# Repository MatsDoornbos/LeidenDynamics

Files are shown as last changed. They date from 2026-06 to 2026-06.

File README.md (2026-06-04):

# Leiden Dynamics Smart Sprinkler System

**Team:** Mats Doornbos, Justin Gruijters, Lucas Idsinga, Benard Wanyande
**Institution:** Leiden University (MSc Robotics)

**Availability Notice:** This repository and all associated files, code, and documentation will remain publicly available and accessible until at least August 31st, 2026.

---

## Repository Contents

*   `Turret_Demo.py`: The main autonomous execution script for scanning, targeting, and firing.
*   `Turret_Calibration.py`: The script used to generate the required trajectory lookup table.
*   `Reloading_Water.py`: A utility script for manually opening and closing the water relay.
*   `/Designs/`: Directory containing CAD models (STEP files) and assembly diagrams for the 3D-printed turret and A-frame fluid system.
*   `SmartSprinkler.mp4`: Video demonstration of the final working system.

## System Requirements

### Hardware Configuration
The software is written specifically for a Raspberry Pi connected to the custom 3D-printed turret and passive-pressure syringe system. Ensure your wiring matches the following configuration for data and power.

**GPIO Pinout (BCM):**
*   **Yaw (Pan) Stepper Motor:** Pins 6, 13, 19, 26
*   **Pitch (Tilt) Stepper Motor:** Pins 12, 16, 20, 21
*   **Pitch Limit Switch (Vertical Home):** Pin 1 (Wired to Ground)
*   **Yaw IR Sensor (Horizontal Home):** Pin 24
*   **Valve Relay:** Pin 25

**Power Supply Wiring:**
*   **5V Power Supply:** Connected directly to the motor power pins to drive the two stepper motors.
*   **12V Power Supply:** Connected via the relay module to provide power to the solenoid valve.
*   **Solenoid Valve:** Wired as a separate circuit, receiving 12V power only when the relay is opened by the Raspberry Pi.

The physical fluid system requires a 500ml syringe filled with water, pressurized by a 9kg weight placed on the plunger.

### Software Dependencies
The system runs on Raspberry Pi OS. You must install the following Python libraries before executing the code:

```bash
sudo apt-get update
sudo apt-get install python3-opencv
pip install RPi.GPIO picamera2 pupil-apriltags gpiozero
```

## Instructions for Use

The system operates strictly via the terminal using the `curses` library. Do not run these scripts inside an IDE (like Thonny), as the keyboard inputs will not register correctly. 

### Step 1: Manual Relay Control (Optional)
If you need to prime the water lines or empty the syringe without moving the motors, run the manual relay script:
```bash
python3 Reloading_Water.py
```
*   Press `o` to open the valve.
*   Press `p` to close the valve.
*   Press `q` to quit.

### Step 2: System Calibration (Required)
The main targeting script cannot calculate water trajectory without calibration data. You must generate a `pitch_calibration.json` file.

1. Ensure the syringe is filled and the 9kg weight is applied.
2. Run the calibration script:
```bash
python3 Turret_Calibration.py
```
3. Press `h` to home the pitch motor against the limit switch.
4. Use `u` and `d` (or `U` and `D` for larger steps) to adjust the pitch angle.
5. Press `f` to fire a burst of water.
6. Measure the horizontal distance from the nozzle to where the water landed in centimeters.
7. Press `r` and type the measured distance to record the data point.
8. Repeat steps 4 through 7 for various pitch angles to create a robust data curve.
9. Press `s` to save the data to `pitch_calibration.json`, then press `q` to quit.

### Step 3: Autonomous Execution
Once `pitch_calibration.json` exists in the same directory, the system can run autonomously.

1. Place AprilTags belonging to the `tag36h11` family on the target plant pots.
2. Run the main targeting script:
```bash
python3 Turret_Demo.py
```
3. The robot will automatically:
   * Home the pitch motor against the limit switch.
   * Home the yaw motor using the IR sensor.
   * Scan 140 degrees to locate all visible AprilTags.
   * Center the camera on each tag.
   * Calculate the required pitch angle using the distance data from the calibration file.
   * Trigger the solenoid valve to fire water into the pot.
   * Return to the home position and await further instruction.
4. Press `q` at any time to safely terminate the program and de-energize the motors and valve.

### Configuration
If the water lands too far in front of or behind the plant pot, open `Turret_Demo.py` in a text editor and adjust the `AIM_OFFSET_CM` variable (default is `5.0`). This value adds a fixed distance to the target calculation to ensure the water lands inside the depth of the pot rather than directly on the front-mounted AprilTag.

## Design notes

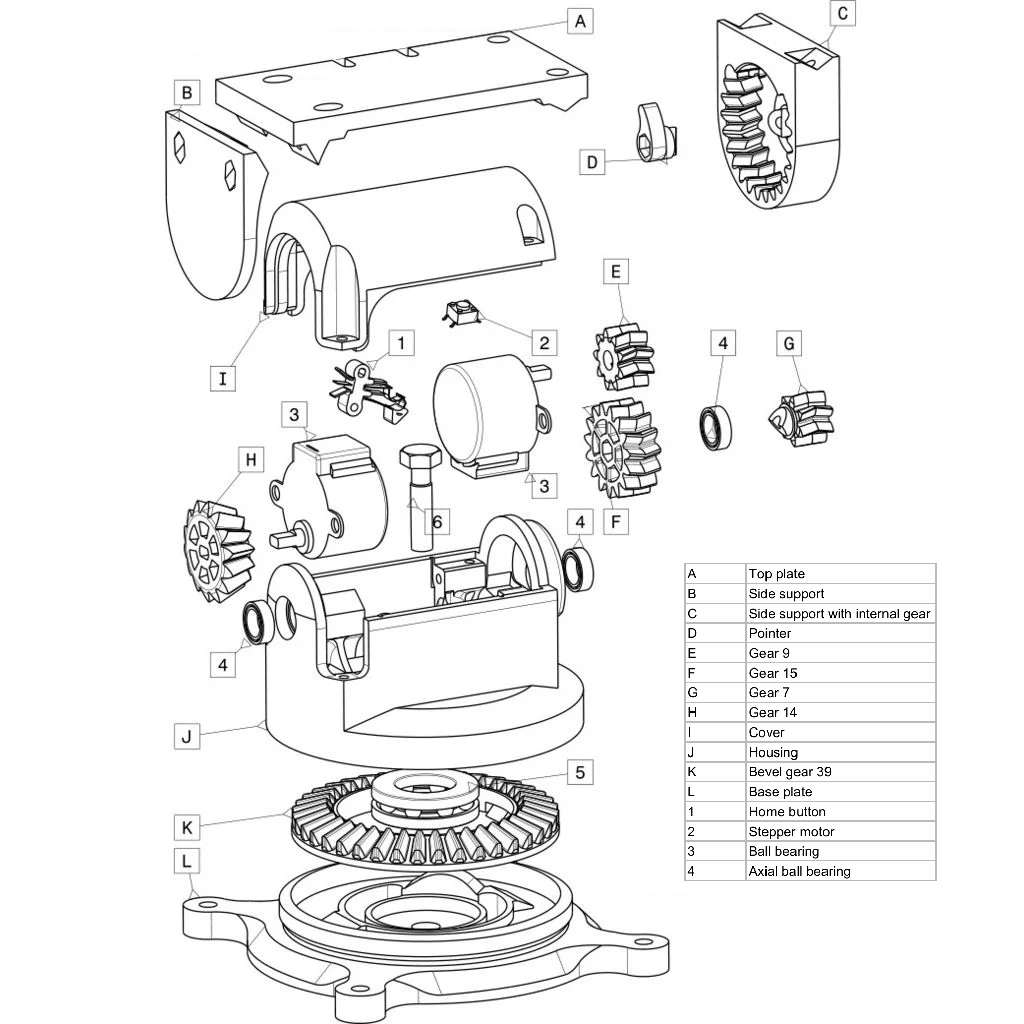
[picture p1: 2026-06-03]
Designs/explodedview_with_table.png

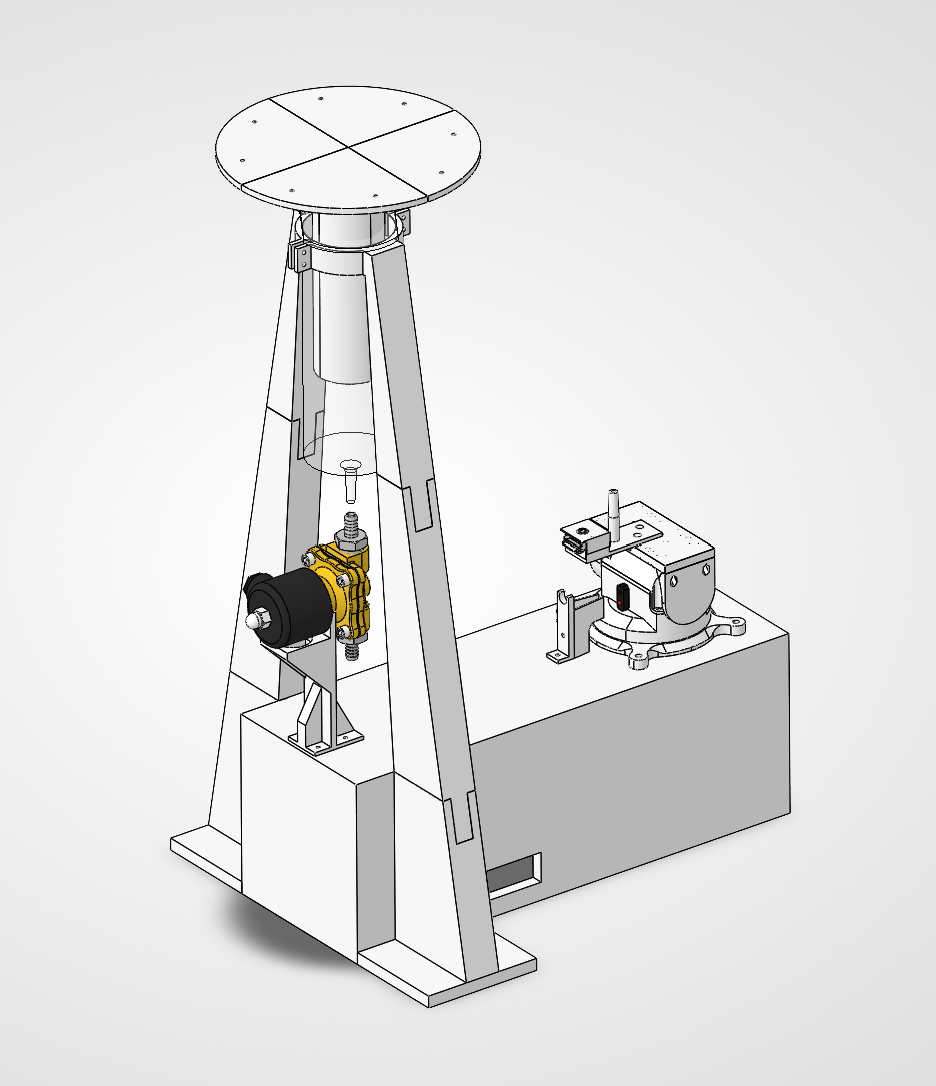
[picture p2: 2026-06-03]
Designs/water robot assm.png

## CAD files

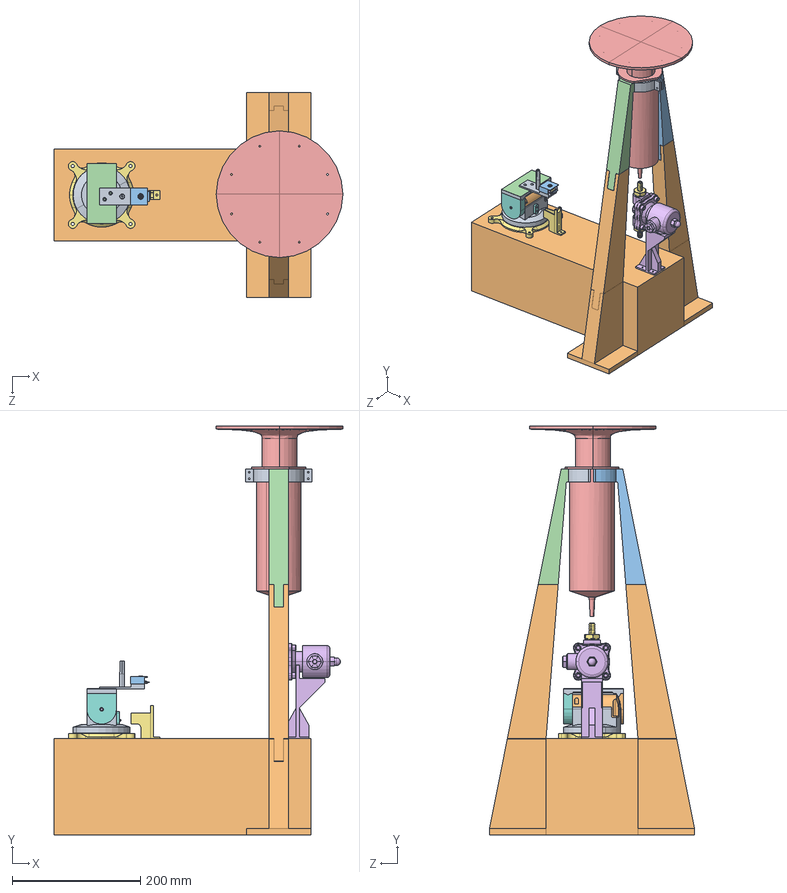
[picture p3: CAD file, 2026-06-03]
Designs/assembly turret.STEP
450.0 x 637.1 x 319.6 mm
turret houder compleet
syringe
User Library-Valvula solenoide 1_2-1_Predeterminado
239_113-E x 2
25.stp
Teil1.stp
Teil2.stp
base.stp
base_1.stp
motor.stp
basisPlatte.stp
Taster.stp
Gehause.stp
Deckel.stp
Schalter.stp
new_top_plate
syringe-skeleton x 4
valve houder
IR sensor houder
IR sensor x 2
camera houderV2
sfw15r3ste1lf.step
Rear Components-0.step
Rear Components-1.step
Rear Components-2.step
Rear Components-3.step
Rear Components-4.step
Sensor.step
Lens.step
Ring.step
Mount.step
Housing.step
Board.step
eBom-FreeParts.step
camera deksel

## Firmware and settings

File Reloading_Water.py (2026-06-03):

"""
relay_trigger.py — simple keyboard relay control for the waterturret.

    'o'  open  (energize the relay)
    'p'  close (de-energize the relay)
    'q'  quit  (also Ctrl+C)

Run with the venv active: `python relay_trigger.py`
"""

from gpiozero import OutputDevice
import sys
import termios
import tty

# --- CONFIGURATION ---------------------------------------------------------

RELAY_PIN = 25       # BCM pin number where the relay's IN is wired

# Most cheap blue relay modules are ACTIVE LOW (relay energizes when the
# GPIO is pulled LOW). Leave False for those. Only set True if your specific
# module is the high-trigger kind.
ACTIVE_HIGH = False

# --------------------------------------------------------------------------

relay = OutputDevice(RELAY_PIN, active_high=ACTIVE_HIGH, initial_value=False)

fd = sys.stdin.fileno()
old_settings = termios.tcgetattr(fd)

try:
    # Raw mode: read each keystroke instantly, no Enter required.
    tty.setraw(fd)

    sys.stdout.write("'o' open  |  'p' close  |  'q' quit\r\n")
    sys.stdout.flush()

    while True:
        ch = sys.stdin.read(1)

        if ch == 'q' or ch == '\x03':   # 'q' or Ctrl+C
            break
        elif ch == 'o':
            relay.on()
            sys.stdout.write("OPEN\r\n")
            sys.stdout.flush()
        elif ch == 'p':
            relay.off()
            sys.stdout.write("CLOSED\r\n")
            sys.stdout.flush()

finally:
    relay.off()
    relay.close()
    termios.tcsetattr(fd, termios.TCSADRAIN, old_settings)
    sys.stdout.write("\r\nDone.\r\n")
    sys.stdout.flush()

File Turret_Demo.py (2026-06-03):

import time
import curses
import sys
import json
import os
import RPi.GPIO as GPIO
from picamera2 import Picamera2
from pupil_apriltags import Detector
import cv2

# --- Pin definitions (BCM) ---
MOTOR_YAW_PINS    = [6, 13, 19, 26]
MOTOR_PITCH_PINS  = [12, 16, 20, 21]
BUTTON_PIN = 1
RELAY_PIN = 25
IR_HOME_PIN = 24

# --- Motor constants ---
STEP_DELAY = 0.002

HALF_STEP_SEQUENCE = [
    [1, 0, 0, 0],
    [1, 1, 0, 0],
    [0, 1, 0, 0],
    [0, 1, 1, 0],
    [0, 0, 1, 0],
    [0, 0, 1, 1],
    [0, 0, 0, 1],
    [1, 0, 0, 1],
]

YAW_LEFT  =  1
YAW_RIGHT = -1
PITCH_UP  = 1
PITCH_DOWN = -1

# Scanning constants
STEPS_PER_DEGREE = 4096 / 360

SCAN_LEFT_DEGREES = 70
SCAN_RIGHT_DEGREES = 140
SCAN_LEFT_STEPS = int(SCAN_LEFT_DEGREES * STEPS_PER_DEGREE)
SCAN_RIGHT_STEPS = int(SCAN_RIGHT_DEGREES * STEPS_PER_DEGREE)
SCAN_STEP_SIZE = 30

# --- Camera constants ---
IMG_W, IMG_H = 1280, 720
CX = IMG_W // 2

CAMERA_PARAMS = (940, 940, 640, 360)
TAG_SIZE = 0.058

# Centering parameters
DEAD_ZONE = 30
STEPS_PER_CORRECTION = 15

# Pitch movement constants
PRE_HOME_BACKOFF_STEPS = 300

# Calibration
SCRIPT_DIR = os.path.dirname(os.path.abspath(__file__))
CALIBRATION_FILE = os.path.join(SCRIPT_DIR, "pitch_calibration.json")
MAX_FIRE_STEPS = 5000   # safety clamp for the pitch motor (just past the new calibration max)


#   "descending"     - higher step count, STEEPER arc (drops into pots from above; default)
#   "ascending"      - lower step count, FLATTER arc (would hit pot fronts; rarely useful)
#   "closer_to_max"  - whichever is closer to peak range
PITCH_PREFERENCE = "descending"

# aim offset to land in pot
AIM_OFFSET_CM = 5.0

# =====================================================================
# Pitch calibration
# =====================================================================

def load_calibration(path):
    """Load calibration data from JSON. Raises on missing or invalid file.
    Prints warnings if the data looks suspiciously incomplete."""
    if not os.path.exists(path):
        raise FileNotFoundError(
            f"Calibration file not found: {path}\n"
            f"Run water_turret_calibrate.py first to create it."
        )
    with open(path) as f:
        data = json.load(f)
    measurements = data.get("measurements", [])
    if len(measurements) < 2:
        raise ValueError(
            f"Calibration file has only {len(measurements)} measurement(s); "
            f"need at least 2 to interpolate."
        )

    # Sanity checks: catch the case where someone reran calibration and
    # accidentally saved just the new measurements instead of merging them
    # with the previous session.
    pts = sorted([(m["steps_from_home"], m["distance_cm"]) for m in measurements])
    max_idx = max(range(len(pts)), key=lambda i: pts[i][1])
    peak_steps, peak_dist = pts[max_idx]

    warnings = []
    if len(measurements) < 5:
        warnings.append(
            f"Only {len(measurements)} measurements — interpolation will be coarse."
        )
    if max_idx == 0:
        warnings.append(
            f"Peak distance ({peak_dist:.0f} cm) is at the LOWEST step count "
            f"({peak_steps}). No ascending-side data present — the curve looks "
            f"one-sided. Did you forget to merge calibration sessions?"
        )
    if max_idx == len(pts) - 1:
        warnings.append(
            f"Peak distance ({peak_dist:.0f} cm) is at the HIGHEST step count "
            f"({peak_steps}). No descending-side data present — the curve looks "
            f"one-sided. Did you forget to merge calibration sessions?"
        )

    if warnings:
        print("WARNING: calibration data may be incomplete:", file=sys.stderr)
        for w in warnings:
            print(f"  - {w}", file=sys.stderr)
        print(f"  File: {path}", file=sys.stderr)
        print(file=sys.stderr)

    return {
        "measurements": measurements,
        "fire_duration_s": float(data.get("fire_duration_s", 2.0)),
        "pressure_kg": data.get("pressure_kg"),
        "nozzle_height_cm": data.get("nozzle_height_cm"),
    }


def pitch_steps_for_distance(distance_cm, measurements,
                             prefer=PITCH_PREFERENCE):
    """
    Distances above the peak are clamped to the peak position.
    Distances below the minimum reachable are clamped to the closest
    measured point.
    """
    if not measurements:
        raise ValueError("No calibration measurements available")

    pts = sorted(
        [(m["steps_from_home"], m["distance_cm"]) for m in measurements],
        key=lambda p: p[0],
    )
    max_idx = max(range(len(pts)), key=lambda i: pts[i][1])
    max_steps, max_distance = pts[max_idx]

    if distance_cm >= max_distance:
        return max_steps

    ascending  = pts[: max_idx + 1]   # distance grows with steps
    descending = pts[max_idx:]        # distance falls with steps

    def interp(target, points):
        distances = [p[1] for p in points]
        if target < min(distances) or target > max(distances):
            return None
        for i in range(len(points) - 1):
            s1, d1 = points[i]
            s2, d2 = points[i + 1]
            if (d1 <= target <= d2) or (d2 <= target <= d1):
                if d1 == d2:
                    return int(round((s1 + s2) / 2))
                t = (target - d1) / (d2 - d1)
                return int(round(s1 + t * (s2 - s1)))
        return None

    asc = interp(distance_cm, ascending)
    desc = interp(distance_cm, descending)

    if asc is None and desc is None:
        # Below minimum reachable; pick the calibration point closest
        # to the requested distance.
        return min(pts, key=lambda p: abs(p[1] - distance_cm))[0]
    if asc is None:
        return desc
    if desc is None:
        return asc

    if prefer == "ascending":
        return asc
    if prefer == "closer_to_max":
        return asc if abs(asc - max_steps) < abs(desc - max_steps) else desc
    return desc


# =====================================================================
# Low-level functions
# =====================================================================

def setup_gpio():
    GPIO.setmode(GPIO.BCM)
    for p in MOTOR_YAW_PINS + MOTOR_PITCH_PINS:
        GPIO.setup(p, GPIO.OUT)
        GPIO.output(p, 0)
    GPIO.setup(BUTTON_PIN, GPIO.IN, pull_up_down=GPIO.PUD_UP)
    GPIO.setup(RELAY_PIN, GPIO.OUT)
    GPIO.output(RELAY_PIN, GPIO.HIGH)
    GPIO.setup(IR_HOME_PIN, GPIO.IN, pull_up_down=GPIO.PUD_UP)


def step_motor(pins, steps, direction=1, on_step=None):

    seq = HALF_STEP_SEQUENCE if direction == 1 else list(reversed(HALF_STEP_SEQUENCE))
    for i in range(steps):
        pattern = seq[i % len(seq)]
        for pin, val in zip(pins, pattern):
            GPIO.output(pin, val)
        time.sleep(STEP_DELAY)
        if on_step is not None and on_step(i + 1):
            for p in pins:
                GPIO.output(p, 0)
            return i + 1
    for p in pins:
        GPIO.output(p, 0)
    return steps


def de_energize_all():
    for p in MOTOR_YAW_PINS + MOTOR_PITCH_PINS:
        GPIO.output(p, 0)


def button_pressed():
    return GPIO.input(BUTTON_PIN) == GPIO.LOW


def ir_home_detected():
    return GPIO.input(IR_HOME_PIN) == GPIO.HIGH


def fire_relay(duration):
    GPIO.output(RELAY_PIN, GPIO.LOW)
    time.sleep(duration)
    GPIO.output(RELAY_PIN, GPIO.HIGH)


def relay_off():
    GPIO.output(RELAY_PIN, GPIO.HIGH)


def status(stdscr, msg):
    stdscr.move(2, 0)
    stdscr.clrtoeol()
    stdscr.addstr(2, 0, msg[:curses.COLS - 1] if curses.COLS else msg)
    stdscr.refresh()


def detail(stdscr, msg):
    stdscr.move(3, 0)
    stdscr.clrtoeol()
    stdscr.addstr(3, 0, msg[:curses.COLS - 1] if curses.COLS else msg)
    stdscr.refresh()


def check_quit(stdscr):
    key = stdscr.getch()
    if key != -1 and chr(key).lower() == 'q':
        return True
    return False


def move_yaw_to(current_pos, target_pos):
    diff = target_pos - current_pos
    if diff > 0:
        step_motor(MOTOR_YAW_PINS, diff, YAW_RIGHT)
    elif diff < 0:
        step_motor(MOTOR_YAW_PINS, abs(diff), YAW_LEFT)
    return target_pos


# =====================================================================
# High-level functions
# =====================================================================

def home_pitch(stdscr):
    while True:
        if check_quit(stdscr):
            return False
        if button_pressed():
            de_energize_all()
            time.sleep(0.3)
            return True
        step_motor(MOTOR_PITCH_PINS, 10, direction=PITCH_UP)


def home_yaw(stdscr, current_pos):
    """
    Return to horizontal home using the IR sensor.

    Sensor wins over odometry

    Returns (True, 0) on success, (False, current_pos) on failure.
    """
    if ir_home_detected():
        status(stdscr, "Already at home (sensor confirms).")
        return True, 0

    # Direction toward home from our position estimate
    if current_pos >= 0:
        direction = YAW_LEFT
        travel = current_pos
    else:
        direction = YAW_RIGHT
        travel = -current_pos

    # Generous travel: estimate plus 50% margin or 500 steps, whichever
    # is larger. This covers significant odometry drift without spinning
    # forever if the sensor is dead.
    margin = max(500, int(travel * 0.5))
    max_travel = travel + margin

    state = {'found': False, 'quit': False}

    def poll(_step):
        if ir_home_detected():
            state['found'] = True
            return True
        key = stdscr.getch()
        if key != -1:
            try:
                if chr(key).lower() == 'q':
                    state['quit'] = True
                    return True
            except ValueError:
                pass
        return False

    dir_name = "LEFT" if direction == YAW_LEFT else "RIGHT"
    status(stdscr, f"Returning home {dir_name} (up to {max_travel} steps, "
                   f"polling sensor every step)...")
    actual = step_motor(MOTOR_YAW_PINS, max_travel, direction, on_step=poll)
    if direction == YAW_RIGHT:
        current_pos += actual
    else:
        current_pos -= actual

    if state['quit']:
        return False, current_pos
    if state['found']:
        status(stdscr, f"Home found after {actual} steps.")
        return True, 0

    # Didn't find it in the expected direction. Reverse and sweep.
    other = YAW_RIGHT if direction == YAW_LEFT else YAW_LEFT
    other_name = "RIGHT" if other == YAW_RIGHT else "LEFT"
    sweep = max_travel + 500
    status(stdscr, f"Not found — sweeping {other_name} (up to {sweep} steps)...")

    state['found'] = False
    actual = step_motor(MOTOR_YAW_PINS, sweep, other, on_step=poll)
    if other == YAW_RIGHT:
        current_pos += actual
    else:
        current_pos -= actual

    if state['quit']:
        return False, current_pos
    if state['found']:
        status(stdscr, f"Home found on reverse sweep ({actual} steps).")
        return True, 0

    status(stdscr, "ERROR: IR home sensor never triggered. Yaw position is unreliable.")
    return False, current_pos


def scan_environment(stdscr, picam, detector):
    detections_log = {}

    status(stdscr, f"Scan: Moving left {SCAN_LEFT_DEGREES} degrees...")
    step_motor(MOTOR_YAW_PINS, SCAN_LEFT_STEPS, YAW_LEFT)
    current_pos = -SCAN_LEFT_STEPS
    time.sleep(0.3)

    status(stdscr, f"Scan: Sweeping right {SCAN_RIGHT_DEGREES} degrees...")
    steps_swept = 0

    while steps_swept < SCAN_RIGHT_STEPS:
        if check_quit(stdscr):
            return None, current_pos

        frame = picam.capture_array()
        frame = cv2.flip(frame, -1)
        gray = cv2.cvtColor(frame, cv2.COLOR_RGB2GRAY)
        detections = detector.detect(
            gray,
            estimate_tag_pose=True,
            camera_params=CAMERA_PARAMS,
            tag_size=TAG_SIZE
        )

        for d in detections:
            tid = d.tag_id
            dist = d.pose_t[2][0]
            if tid not in detections_log:
                detections_log[tid] = []
            detections_log[tid].append((current_pos, dist))

        tag_ids_here = [d.tag_id for d in detections]
        found_so_far = len(detections_log)
        deg_from_start = current_pos / STEPS_PER_DEGREE
        detail(stdscr, f"Pos:{deg_from_start:+.0f}deg  Here:{tag_ids_here}  Found:{found_so_far}")

        actual_step = min(SCAN_STEP_SIZE, SCAN_RIGHT_STEPS - steps_swept)
        step_motor(MOTOR_YAW_PINS, actual_step, YAW_RIGHT)
        current_pos += actual_step
        steps_swept += actual_step

    targets = []
    for tag_id, observations in detections_log.items():
        positions = sorted([p for p, d in observations])
        distances = [d for p, d in observations]
        median_pos = positions[len(positions) // 2]
        avg_dist = sum(distances) / len(distances)
        targets.append({
            'tag_id': tag_id,
            'step_pos': median_pos,
            'distance': avg_dist,
        })

    return targets, current_pos


def nearest_neighbor_order(targets, start_pos):
    remaining = list(targets)
    ordered = []
    pos = start_pos

    while remaining:
        nearest_idx = 0
        nearest_dist = abs(remaining[0]['step_pos'] - pos)
        for i, t in enumerate(remaining):
            d = abs(t['step_pos'] - pos)
            if d < nearest_dist:
                nearest_dist = d
                nearest_idx = i

        chosen = remaining.pop(nearest_idx)
        ordered.append(chosen)
        pos = chosen['step_pos']

    return ordered


def center_on_tag(stdscr, picam, detector, current_pos, expected_tag_id):
    centered_count = 0
    tag_distance = None
    attempts = 0
    max_attempts = 200

    while attempts < max_attempts:
        attempts += 1
        if check_quit(stdscr):
            return False, current_pos, None

        frame = picam.capture_array()
        frame = cv2.flip(frame, -1)
        gray = cv2.cvtColor(frame, cv2.COLOR_RGB2GRAY)
        detections = detector.detect(
            gray,
            estimate_tag_pose=True,
            camera_params=CAMERA_PARAMS,
            tag_size=TAG_SIZE
        )

        # Filter to the specific tag we're trying to engage. Two tags can
        # share the camera frame; without this filter we'd lock onto
        # whichever one happens to be detections[0], which is often not
        # the target we just slewed yaw to.
        matching = [d for d in detections if d.tag_id == expected_tag_id]

        if not matching:
            detail(stdscr, f"Tag {expected_tag_id} not in view — waiting...")
            centered_count = 0
            time.sleep(0.1)
            continue

        tag = matching[0]
        tx = tag.center[0]
        dx = tx - CX
        tag_distance = tag.pose_t[2][0]

        if abs(dx) <= DEAD_ZONE:
            centered_count += 1
            detail(stdscr, f"CENTERED ({dx:+.0f}px) [{centered_count}/5] d={tag_distance:.2f}m")
            if centered_count >= 5:
                return True, current_pos, tag_distance
            time.sleep(0.05)
            continue

        centered_count = 0

        if dx > 0:
            step_motor(MOTOR_YAW_PINS, STEPS_PER_CORRECTION, YAW_RIGHT)
            current_pos += STEPS_PER_CORRECTION
        else:
            step_motor(MOTOR_YAW_PINS, STEPS_PER_CORRECTION, YAW_LEFT)
            current_pos -= STEPS_PER_CORRECTION

        detail(stdscr, f"Centering: offset {dx:+.0f}px | pos={current_pos}")

    return False, current_pos, tag_distance


def fire_sequence(stdscr, target_distance_cm, calibration):
    """
    Pitch to the calibrated angle for the target distance, fire for the
    calibrated duration, then return to home.
    """
    measurements = calibration["measurements"]
    fire_duration = calibration["fire_duration_s"]

    fire_steps = pitch_steps_for_distance(target_distance_cm, measurements)
    # Safety clamp — never command a position outside the soft range
    fire_steps = max(0, min(fire_steps, MAX_FIRE_STEPS))

    status(stdscr, "Preparing: vertical home...")
    step_motor(MOTOR_PITCH_PINS, PRE_HOME_BACKOFF_STEPS, direction=PITCH_DOWN)
    de_energize_all()
    time.sleep(0.2)
    if not home_pitch(stdscr):
        return False

    status(stdscr, f"Pitching to {fire_steps} steps "
                   f"for target at {target_distance_cm:.0f} cm...")
    step_motor(MOTOR_PITCH_PINS, fire_steps, direction=PITCH_DOWN)
    de_energize_all()
    time.sleep(0.5)

    status(stdscr, f"FIRING for {fire_duration:.1f}s!")
    fire_relay(fire_duration)
    time.sleep(0.5)

    status(stdscr, "Returning to vertical home...")
    step_motor(MOTOR_PITCH_PINS, PRE_HOME_BACKOFF_STEPS, direction=PITCH_DOWN)
    de_energize_all()
    time.sleep(0.2)
    if not home_pitch(stdscr):
        return False

    return True


# =====================================================================
# Main
# =====================================================================

def main(stdscr, calibration):
    curses.curs_set(0)
    stdscr.nodelay(True)
    stdscr.clear()

    setup_gpio()

    picam = Picamera2()
    config = picam.create_video_configuration(main={"size": (IMG_W, IMG_H), "format": "RGB888"})
    picam.configure(config)
    picam.start()
    time.sleep(1)

    detector = Detector(families="tag36h11")
    current_pos = 0

    try:
        n_measurements = len(calibration['measurements'])
        stdscr.addstr(0, 0,
            f"=== WATER TURRET === ({n_measurements} cal pts, "
            f"fire={calibration['fire_duration_s']}s) (Q to quit)")
        stdscr.refresh()

        # ==========================================================
        # PHASE 1: Initial home (both axes)
        # ==========================================================
        status(stdscr, "Phase 1: Vertical home...")
        step_motor(MOTOR_PITCH_PINS, PRE_HOME_BACKOFF_STEPS, direction=PITCH_DOWN)
        de_energize_all()
        time.sleep(0.2)
        if not home_pitch(stdscr):
            return

        status(stdscr, "Phase 1: Verifying horizontal home (IR sensor)...")
        if not ir_home_detected():
            status(stdscr, "ERROR: Not at home! Manually center the turret so the IR sensor")
            detail(stdscr, "triggers, then restart. Press Q to quit.")
            while not check_quit(stdscr):
                time.sleep(0.1)
            return
        status(stdscr, "Phase 1: At horizontal home.")
        current_pos = 0
        time.sleep(0.5)

        # ==========================================================
        # PHASE 2: Scan environment
        # ==========================================================
        status(stdscr, "Phase 2: Scanning...")
        time.sleep(0.5)

        targets, current_pos = scan_environment(stdscr, picam, detector)
        if targets is None:
            return

        if len(targets) == 0:
            status(stdscr, "No tags found. Returning home...")
            success, current_pos = home_yaw(stdscr, current_pos)
            status(stdscr, "Home. No targets. Press Q.")
            while not check_quit(stdscr):
                time.sleep(0.1)
            return

        targets = nearest_neighbor_order(targets, current_pos)

        tag_summary = ", ".join([
            f"ID{t['tag_id']}({t['step_pos']/STEPS_PER_DEGREE:+.0f}deg)"
            for t in targets
        ])
        status(stdscr, f"Found {len(targets)}: {tag_summary}")
        detail(stdscr, "Starting engagement...")
        time.sleep(2)

        # ==========================================================
        # PHASE 3: Engage each target
        # ==========================================================
        for i, target in enumerate(targets):
            deg = target['step_pos'] / STEPS_PER_DEGREE
            status(stdscr, f"[{i+1}/{len(targets)}] Tag {target['tag_id']} "
                           f"({deg:+.0f}deg, ~{target['distance']:.2f}m)")

            current_pos = move_yaw_to(current_pos, target['step_pos'])
            time.sleep(0.3)

            detail(stdscr, "Fine centering...")
            success, current_pos, distance_m = center_on_tag(
                stdscr, picam, detector, current_pos, target['tag_id']
            )

            if not success:
                detail(stdscr, f"Could not center on tag {target['tag_id']} — skipping")
                time.sleep(1)
                continue

            # Tag pose distance is in meters; calibration is in cm.
            # Add AIM_OFFSET_CM so we shoot into the pot (which extends
            # behind the tag), not at the tag itself.
            tag_distance_cm = distance_m * 100.0
            target_distance_cm = tag_distance_cm + AIM_OFFSET_CM

            status(stdscr, f"Locked: tag {target['tag_id']} at "
                           f"{tag_distance_cm:.0f} cm "
                           f"(aim {target_distance_cm:.0f} cm)")

            if not fire_sequence(stdscr, target_distance_cm, calibration):
                return

            status(stdscr, f"Tag {target['tag_id']} done! ({i+1}/{len(targets)})")
            detail(stdscr, "")
            time.sleep(1)

        # ==========================================================
        # PHASE 4: Return to home
        # ==========================================================
        success, current_pos = home_yaw(stdscr, current_pos)
        if not success:
            return

        status(stdscr, "HOME. All targets engaged. Press Q.")
        while not check_quit(stdscr):
            time.sleep(0.1)

    except KeyboardInterrupt:
        pass
    finally:
        relay_off()
        de_energize_all()
        picam.stop()
        GPIO.cleanup()
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
